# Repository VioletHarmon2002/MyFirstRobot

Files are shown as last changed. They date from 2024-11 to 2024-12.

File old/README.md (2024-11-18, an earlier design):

# Little endian 2.0

A HvA IoT project by Timo Lambregts, Jayden van Oorschot, Luc Enderman, Floris Boers, Gjalt van der Meer, Ilias Takassa and Silvester Rademakers.

You can find all relevant documentation 
[here](https://faaxeeheeqee80-iot-2023-2024-semester-2-group-pr-eb151c272401a9.dev.hihva.nl/)

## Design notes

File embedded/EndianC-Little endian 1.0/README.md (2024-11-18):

# Little endian base files

This repository contains the base design files and custom arduino libraries to create and work with the little endian robot.

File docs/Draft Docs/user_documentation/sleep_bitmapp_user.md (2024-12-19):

## User Documentation

### Using the Sleep Emote
The sleep emote is a visual representation of a sleeping state for the robot. 

#### Activating the Sleep Emote
To activate the sleep emote:

1. Ensure your device is powered on and connected to the OLED display.
2. Send the "sleep" command to your device using website of the project, for example.
3. The OLED display should now show the sleep emote.

### Troubleshooting
If the sleep emote doesn't display correctly:

1. Verify that the `sleep_bitmap.h` file is in the same directory as your main sketch.
2. Check that the bitmap dimensions are correct and match the actual size of your bitmap data.
3. Ensure that the OLED display is properly connected and initialized in your code.

### Customization
If you wish to modify the sleep emote:

1. Open the `sleep_bitmap.h` file in a text editor.
2. Modify the bitmap data array to change the appearance of the emote.
3. Ensure that the `sleep_width` and `sleep_height` definitions match your modifications if you change the size of the bitmap.

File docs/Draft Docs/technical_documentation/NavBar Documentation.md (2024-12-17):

# Overview

This script dynamically loads a navigation bar into the webpage and sets the active link based on the current page. It ensures that the correct nav link is highlighted, providing a visual to the user about their current location within the website

# Code breakdown

**Event Listener** : `document.addEventListener("DOMContentLoaded", function ()`

**Fetch NavBar.html**: 
```
fetch('NavBar.html')
.then(response => response.text())
.then(data => { document.getElementById('navbar').innerHTML = data;
```

- This fetches the `NavBar.html` file.
- Converts the response to text
- Inserts the fetched file's content into the element with the ID `navbar`

**Determine the current page**

With this code `const currentPage = window.location.pathname.split("/").pop();` The current page's filename is fetched from the URL

**Map pages to link ID's**

```
const pageToLinkMap = {
    "arrows.html": "robot-controls-link",
    "blocky.html": "block-editor-link",
    "connect.html": "connect-robot-link",
};
```

Then we get the active Link ID using this line

`const activeLinkId = pageToLinkMap[currentPage];`

Then we use the current pag'es filename to get the link ID from the `pageToLinkMap`

**Set the active link**

With this code we set the active link

```javascript
if (activeLinkId) {
    const activeLink = document.getElementById(activeLinkId);
    if (activeLink) {
        activeLink.classList.add("active");
    }
}
```

**Error Handling**

With this line we handle the errors incase the link doesn't exist

`.catch(error => console.error('Error loading navbar:', error));`

# Navigation Buttons to Nav Bar [#144]
The navigation buttons have been replaced with a responsive top navigation bar for seamless navigation across pages. The existing NavBarLoader functionality has been retained to dynamically highlight the current page.

**For Developers**
Changes Made:

1. HTML:  
Added a <nav> element with structured navigation links inside an unordered list (<ul>).

````
<nav id="navbar">
    <ul class="nav-list">
        <li><a href="arrows.html" id="robot-controls-link" class="nav-link">Robot Controls</a></li>
        <li><a href="blocky.html" id="block-editor-link" class="nav-link">Block Editor</a></li>
        <li><a href="connect.html" id="connect-robot-link" class="nav-link">Connect</a></li>
    </ul>
</nav>
````

2. CSS:  
Styled the navbar for a horizontal layout with hover effects, active link indicators, and responsive design for smaller screens.

````
.nav-list { list-style: none; display: flex; gap: 24px; }
.nav-link:hover { color: var(--color-sweet); }
.active { border-bottom: 2px solid var(--color-sweet); }
````

**For Users**  
- Improved Navigation: The navigation bar is fixed at the top for easy access across all pages.  
- Interactive Design: Hover effects and active link highlighting enhance usability.  
- Responsive Layout: Adapts seamlessly to various screen sizes for a consistent experience.

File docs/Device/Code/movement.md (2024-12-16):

# Robot Movement
### Walking Function Refactoring  
I implemented the forward-walking functionality for the robot and documented the progress in [User Story #114](https://gitlab.fdmci.hva.nl/IoT/2024-2025-semester-1/group-project/poonuugaaqii15/-/issues/114).

#### Key Changes:
- **Modular Design:**  
  - Extracted the `walkForward` function from the main file to a separate header file to improve code organization and readability.  
  - Created a dedicated **`walking.h`** file to encapsulate walking-related functions.

#### Benefits:
- **Clean Codebase:** The main file is now more concise and focused.  
- **Future Expansion:** The `walking.h` file provides a reusable structure for implementing additional walking movements.
---

### Issues Encountered and Fixes Implemented

#### 1. **Incorrect Use of `switch` with Strings**
- **Issue:**  
  The function `getCommand` attempted to use a `switch` statement with `String` objects, which is not supported in C++.
  
  ```cpp
  Command getCommand(const String& command) {
    switch(command) {  // Error: switch cannot be used with strings.
      case "forward":
        return FORWARD;
      // ...
    }
  }
  ```
  
- **Solution:**  
  Replace the `switch` statement with a series of `if-else` conditions or use a `std::map` for cleaner implementation.

  **Updated Code Example:**  
  ```cpp
  Command getCommand(const String& command) {
    if (command == "forward") return FORWARD;
    else if (command == "backward") return BACKWARD;
    // ... other conditions
    else return UNKNOWN;
  }
  ```

#### 2. **Duplicate Command Check**
- **Issue:**  
  The `"dance"` command was repeated in the conditional statement, which could lead to redundancy and confusion:
  
  ```cpp
  } else if (command == "forward" || command == "backward" || command == "dance" || command == "dance") {
  ```

- **Solution:**  
  Remove the duplicate `"dance"` condition to simplify and avoid redundancy.

  **Corrected Code Example:**  
  ```cpp
  } else if (command == "forward" || command == "backward" || command == "dance") {
  ```

#### **Key Takeaways:**
- **C++ Limitations:** Remember that `switch` statements do not support strings; use `if-else` or lookup structures instead.
- **Code Review:** Always review conditional statements for duplicate checks to ensure efficiency and clarity.

---  

### Laying Down Function Refactoring
I implemented the lieDown function so that the robot can lay down: [User Story #106](https://gitlab.fdmci.hva.nl/IoT/2024-2025-semester-1/group-project/poonuugaaqii15/-/issues/106).

#### For Developers
The lieDown function is placed in a separate header file (lieDown.h) for maintainability and reusability. Separating this functionality from the main file makes the codebase more organized and easier to modify. By storing the servo angles in an array, the function is both readable and simple to adjust.

**How It Works:**

The lieDown function accepts four servo objects representing the legs of the robot:  

- Front Left (FL)
- Front Right (FR)
- Rear Left (RL)
- Rear Right (RR)

The predefined servo positions for the lying-down motion are stored in the lieDownPositions array:  
{0, 180, 180, 0}.  

These correspond to specific angles for each leg:  

- 0° for the Front Left leg
- 180° for the Front Right leg
- 180° for the Rear Left leg
- 0° for the Rear Right leg

When the function is called, each servo is commanded to move to the assigned angle using the write method.

#### For End Users
The lieDown function allows the robot to smoothly transition into a lying-down position. This motion should be visually natural, with each leg moving to a predefined angle.

**How It Works:**

- Upon activating the "lie down" command, the robot's legs are adjusted via its servo motors to specific angles.  
- The motion ensures that the robot adopts a stable and balanced lying posture.

**Key Features:**

- The function ensures smooth movement of the robot.
- Predefined positions make the movement accurate and repeatable.
- The design is efficient, enabling reliable execution of the lying-down motion.

### Sit Function
The sit() function is designed to move the servos of the robot to predefined positions that simulate a sitting posture. It is part of the Movement class and works with initialized servo motors to adjust the robot's legs accordingly.

#### For Developers  
**How it Works:** The function writes specific angles to each servo based on predefined "sit" positions stored in an array:

````
 int sitPosition[] = {110, 40, 70, 145}; // Angles for FL, FR, RL, RR servos
````

These values correspond to the optimal configuration for a sitting position.

**Function Details:**

````
void sit();
````

- Location: Defined in movement.cpp.  
- Access: Public method in the Movement class.  
- Purpose: Moves the robot into a seated position by writing specific angles to each leg servo.

#### For End Users  
**What it Does:** Transitions the robot into a sitting position by moving its legs to predefined angles.  
**When to Use:** Use this function when you want the robot to adopt a seated posture for resting or stabilization. The movement can be controlled via the web application when the "sit" command is pressed. The robot dog will then follow the instruction.

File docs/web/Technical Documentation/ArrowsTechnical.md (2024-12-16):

# Technical Documentation of arrows HTML

### Overview

This code provides a web-based control page for the robot, allowing users to issue commands for animations, emotes and movement through buttons. These commands are sent to the server using a TCP socket.

#### HTML Structure

- Container for Buttons: Groups buttons for animations, emotes, and movement into distinct sections.

- Button Elements: Each button sends a specific command to the server when clicked.

#### Key Classes:

- `.animate-container`: Contains buttons for animations.
- `.emote-container`: Contains buttons for emotes.
- `.arrow-container`: Contains directional movement buttons.

#### Supported Commands

- **Animation commands**: `Stand`, `Sit`, `Lay`, `Wave`
- **Emote commands**: `Smile`, `Frown`, `Cry`, `Sleep`
- **Movement commands**: `Forward`, `Backward`, `Left`, `Right`

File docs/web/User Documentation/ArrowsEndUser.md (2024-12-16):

# End user documentation

### Purpose

This interface allows you to controll a robot's movements, animations and emotes using simple buttons.

#### Features

1. **Animations**
    - `Stand`: Makes the robot stand upright.
    - `Sit`: Puts the robot in a seated position.
    - `Lay Down`: Makes the robot lie down.
    - `Wave`: The robot waves its paw.

2. **Emotes**
    - `Smile`: The robot displays a smiling expression.
    - `Frown`: The robot shows a frowning expression.
    - `Cry`: The robot simulates crying.
    - `Sleep`: The robot enters a sleeping pose.

3. **Movement**
    - `Direction controls`: Buttons to move the robot forward, backward, left or right

#### Troubleshooting

1. **No response from robot**
    - Ensure the robot is powered on and connected to the network

2. **Error messages**
    - `Failed to create socket`: The control page has an issue, try restarting it.
    - `Failed to connect to server`: The robot is either offline or there is something wrong with the server

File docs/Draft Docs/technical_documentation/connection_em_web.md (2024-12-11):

# Documentation for Robot Network Code

## Overview
This project establishes a robot’s network connectivity and command-handling capabilities, with key components for Wi-Fi management and WebSocket communication. It uses modular classes for better separation of concerns and code readability.

---

## WebSocket Handler
The `WebSocketClient` class in **`websocket_handler.cpp`** handles WebSocket communication with a remote server.

### Key Features
- **Connect to a server**:
  - `Connect()` establishes a WebSocket connection with the server.
  - `Reconnect()` retries connecting if the connection is lost.
- **Send and receive data**:
  - `SendData(const String& data)` sends JSON data to the server.
  - `ReadData()` reads JSON data from the server, deserializing it to extract the command.
- **Connection management**:
  - `IsConnected()` checks the connection status.
  - `CloseConnection()` safely disconnects the client.

### Code Highlights
#### Constructor
```cpp
WebSocketClient::WebSocketClient(const char* ip, uint16_t port) 
    : server_ip(ip), server_port(port) {}
```
Initializes the WebSocket client with server IP and port.

#### JSON Handling in `ReadData`
```cpp
DynamicJsonDocument doc(1024);
DeserializationError error = deserializeJson(doc, json);
if (error) {
  Serial.print("JSON deserialization failed: ");
  Serial.println(error.c_str());
  return;
}
```
Parses incoming JSON strings to extract commands, while handling deserialization errors.

---

## Wi-Fi Manager
The `WiFiManagerHelper` class in **`wifi_manager.cpp`** manages Wi-Fi connectivity using the WiFiManager library.

### Key Features
- **Automatic Wi-Fi connection**:
  - `connectToWiFi(const char* ssid)` attempts to connect to a specified Wi-Fi network, retrying up to 5 times.
- **Custom callbacks**:
  - `setOnConnectionFailedCallback(std::function<void()> callback)` allows specifying a custom action for connection failures.
- **Access to Wi-Fi client**:
  - `getClient()` provides a reference to the `WiFiClient` instance for use in other modules.

### Code Highlights
#### Connection Retry Logic
```cpp
for (int attempt = 1; attempt <= maxRetries; ++attempt) {
    if (wifiManager.autoConnect(ssid)) {
        Serial.println("Connected to WiFi");
        return true;
    } else {
        Serial.printf("Connection attempt %d failed, retrying...\n", attempt);
        delay(retryDelay);
    }
}
```
This loop attempts reconnection, providing feedback on each attempt.

---

## Main Program
The main program (**`main.cpp`**) integrates Wi-Fi and WebSocket components while coordinating robot functionalities such as movement and face display.

### Wi-Fi Manager Integration
#### Connecting to Wi-Fi
```cpp
if (!wifiManagerHelper.connectToWiFi()) {
    Serial.println("Wi-Fi connection failed");
    ESP.restart();  // Restart ESP32 if Wi-Fi connection fails
}
```
Ensures the robot is connected to Wi-Fi and restarts if the connection cannot be established.

### WebSocket Handler Integration
#### Establishing Connection
```cpp
if (!wsClient.Connect()) {
    Serial.println("Failed to connect to the server");
    ESP.restart();  // Restart the ESP32 if connection fails
}
```
Connects to the server on startup and restarts if the connection fails.

#### Receiving Commands
```cpp
if (wsClient.IsConnected()) {
    String command = wsClient.ReadData();
    setFace(command);
    handleCommand(command);
}
```
Handles incoming JSON commands, updating the robot’s face and movements based on the received instructions.

---

## Dependencies
- **WiFiManager**: Simplifies Wi-Fi connection setup.
- **ArduinoJson**: Enables parsing and serialization of JSON data.
- **Wire**: Handles I2C communication for sensors and displays.
- **ESP32Servo**: Manages servo motors for movement.

---

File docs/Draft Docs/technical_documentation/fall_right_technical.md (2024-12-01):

# `fall_right.h` Technical Documentation

## Overview  
The `fall_right.h` file defines a function to initiate a controlled fall of the robot to its right side using servo motors. The ESP32Servo library is used for servo control, ensuring precise positioning of the robot.

---

## Dependencies  
- **Library**: `ESP32Servo.h`  
  Required for controlling servo motors on ESP32 devices.

---

## Constants

const int fallRightPositions[4] = {0, 0, 180, 180};

- Defines the servo positions for a controlled right-side fall.
- The order of servo positions:
  1. **FL** - Front Left (0°)
  2. **FR** - Front Right (0°)
  3. **RL** - Rear Left (180°)
  4. **RR** - Rear Right (180°)

---

## Functions

### `void fallRight(Servo& FL, Servo& FR, Servo& RL, Servo& RR)`  
Initiates the robot's fall to the right by setting the servo motors.

#### Parameters:
- **`FL`**: Front Left servo motor
- **`FR`**: Front Right servo motor
- **`RL`**: Rear Left servo motor
- **`RR`**: Rear Right servo motor

#### Behavior:
1. **Prints**: "Falling to the right" to the serial monitor for debugging.

---

## Example Usage

#include <ESP32Servo.h>
#include "fall_right.h"

// Servo Initialization
Servo frontLeft;
Servo frontRight;
Servo rearLeft;
Servo rearRight;

void setup() {
    Serial.begin(9600);
    
    // Attach servos to appropriate pins
    frontLeft.attach(2);  // Example 
    frontRight.attach(4); // Example 
    rearLeft.attach(5);   // Example 
    rearRight.attach(18); // Example 
}

void loop() {
    // Trigger the controlled fall
    fallRight(frontLeft, frontRight, rearLeft, rearRight);
    delay(5000);  // Delay for demonstration
}
```

---

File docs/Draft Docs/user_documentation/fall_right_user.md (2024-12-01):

# Fall Right Module - User Documentation

## Overview

The Fall Right module provides a function to adjust the servos of the Little Endian robot when it is falling to the right. This function is intended to be used as part of a larger system that detects falls and triggers appropriate responses.

## Features

- Adjusts the servos to predefined positions to help stabilize the robot.
- Simple integration with existing servo control systems.

## How to Use

1. **Setup**: Ensure that the servos are properly connected to the robot's control board and are initialized using the `ESP32Servo` library.
2. **Function Call**: Use the `fallRight` function to adjust the servos when a right-side fall is detected.
3. **Integration**: Integrate this function into your fall detection system to automatically trigger servo adjustments.

## Troubleshooting

- **Servo Movement Issues**: If the servos do not move as expected, check the connections and ensure the servos are properly initialized.

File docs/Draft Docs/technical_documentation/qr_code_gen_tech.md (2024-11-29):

# Description

This code generates a QR code from the MAC address of an ESP32 device and prints it to the Serial Monitor.
The QR code is displayed using ██ for black modules and spaces for white modules. This will turn into the QR code that end users will scan to controll the robot.

## Dependencies

- `Wifi.h`: Library for WiFi functions.
- `qrcodegen.h`: Library for generating QR codes.

## Functions

`void printQRCode(const uint8_t qrcode[])`

This function prints the QR code to the Serial Monitor.

- int size = qrcodegen_getSize(qrcode): Retrieves the size of the QR code.
- Serial.print("QR code size: "): Prints the size of the QR code.
- for (int y = 0; y < size; y++): Iterates over each row of the QR code.
- for (int x = 0; x < size; x++): Iterates over each column of the QR code.
- Serial.print(qrcodegen_getModule(qrcode, x, y) ? "██" : " "): Prints ██ for black modules and spaces for white modules.

## Example output

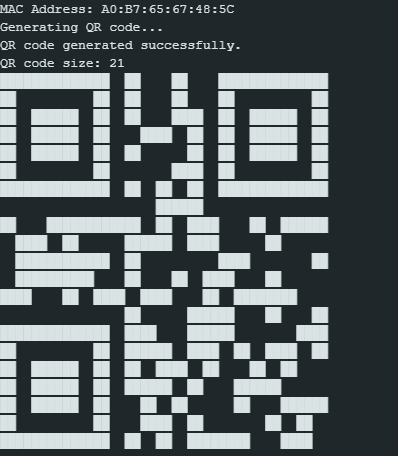
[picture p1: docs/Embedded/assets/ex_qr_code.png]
Example output


## Source code

```c++
void setup() {
  Serial.begin(115200);

  delay(1000);

  WiFi.mode(WIFI_MODE_STA);
  WiFi.begin();

  delay(100);

  String macAddress = WiFi.macAddress();

  Serial.println("MAC Address: " + macAddress);

  const int bufferSize = qrcodegen_BUFFER_LEN_FOR_VERSION(3);
  uint8_t qrcode[bufferSize];
  uint8_t tempBuffer[bufferSize];

  Serial.println("Generating QR code...");
  bool success = qrcodegen_encodeText(macAddress.c_str(), tempBuffer, qrcode, qrcodegen_Ecc_LOW,
                                      qrcodegen_VERSION_MIN, qrcodegen_VERSION_MAX, qrcodegen_Mask_AUTO, true);

  if (success) {
    Serial.println("QR code generated successfully.");
    printQRCode(qrcode);
  } else {
    Serial.println("Failed to generate QR code.");
  }
}
```

```c++
void printQRCode(const uint8_t qrcode[]) {
  int size = qrcodegen_getSize(qrcode);
  Serial.print("QR code size: ");
  Serial.println(size);
  for (int y = 0; y < size; y++) {
    for (int x = 0; x < size; x++) {
      Serial.print(qrcodegen_getModule(qrcode, x, y) ? "██" : "  ");
    }
    Serial.println();
  }
}
```

## Steps to generate QR Code

#### prerequisites

1. Download the zip of the qr code generator library by nayuki at this 
[link](https://github.com/nayuki/QR-Code-generator)

2. Follow these steps for the library:
- Extract the zip file
- Copy the `c` folder
- Paste the `c` folder in the `libraries` folder of Arduino IDE, usually located at `Documents/Arduino/libraries`
- Rename the `c` folder to `QRCode`
- Remove the `qrcodegen-demo` and the `qrcodegen-test` files

#### Generate QR code

1. Upload the code to your board:
- Connect your board(e.g ESP32) to your computer
- Open the Arduino IDE
- Copy and paste the code
- Upload the code to your board
2. Open the serial monitor:
- After uploading the code, open the serial monitor
- set the baud rate to `115200`
3. Generate the QR code
- The board will display a mac adress
- it will then generate a QR code from the MAC adress and print it to the serial monitor.

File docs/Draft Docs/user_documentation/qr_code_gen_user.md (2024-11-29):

# End User Documentation

## Description

This document provides instructions for connecting to and controlling a robot using a QR code generated by the ESP32. The QR code contains the id of the ESP32, which is used to establish a connection.

## Connecting to the robot

1. Scan the QR Code:

- Use a QR code scanner on your smartphone or a dedicated QR code scanning device.
- Scan the printed QR code to connect to the robot

2. Control the Robot:

- Once connected, you can use the robot control application to send commands to the robot.
- Use the provided controls to control the robot.

## Example QR Code

Here's an example of what the QR code might look like:

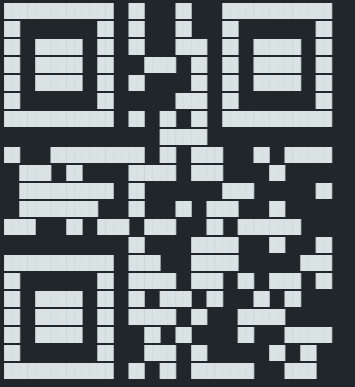
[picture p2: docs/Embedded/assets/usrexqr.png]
ExampleQRCode


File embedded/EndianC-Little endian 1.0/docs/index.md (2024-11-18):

## Motor_test

An arduino sketch to test the steppermotors and the shift registers

## Accelstepper

Copy this folder to your Arduino/libaries folder for the LEAccelStepper to work. This is the original Accelstepper library with a small change to make it possible to extend it and use shift registers.

Read the original [AccelStepper documentation](https://www.airspayce.com/mikem/arduino/AccelStepper/) for more information.

## PCB Design

The PCB contains the following components:

### 74HC595 shift register

This component is used so the WEMOS D1 Mini needs less pins to control the steppermotors. The shift register is connected to the WEMOS D1 Mini with the following pins:

| WEMOS D1 Mini | 74HC595 |
| --- | --- |
| D0 | DS |
| D4 | SCHP |
| D5 | STCP |

By setting these 3 pins HIGH or LOW in a specific order, you can control the 8 output pins of the shift register. 

### ULN2003A transistor array

This component is used to control the steppermotors by diverting power directly from the battery or USB to the stepper motor coils. The ULN2003A is connected to the shift register in the following way:

| 74HC595 | ULN2003A | motor |
| --- | --- | --- |
| Q0 | IN1 | Motor 2, Pin 4 |
| Q1 | IN2 | Motor 2, Pin 3 |
| Q2 | IN3 | Motor 2, Pin 2 |
| Q3 | IN4 | Motor 2, Pin 1 |
| Q4 | IN5 | Motor 1, Pin 4 |
| Q5 | IN6 | Motor 1, Pin 3 |
| Q6 | IN7 | Motor 1, Pin 2 |
| Q7 | IN8 | Motor 1, Pin 1 |

### RGB LED

An WS2812 RGB LED is connected with its datapin to pin D4 on the WEMOS. You can use the Adafruit NeoPixel library to control the LED.

### Battery

The PCB can be powered by four AA batteries. The batteries are connected to the PCB with a JST connector. The battery power can be switched on or off using a switch between connected to `JP3`.

### External devices

The I2C (SCL and SDA) pins of the WEMOS are connected to multiple JST connectors in order to connect external peripherals. These pins (D1 and D2) can also be used as GPIO pins.

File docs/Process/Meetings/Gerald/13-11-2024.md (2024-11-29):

# Meeting Gerald 13 November

Continue on the existing assignment. The documentation is already present. 

**Problems:**

- Not really usable for the target audience
- Non functional web app
- Not working with multiple robots.
- Design flaws hardware robot
- Capacitors for voltage drop servos
- Motions hardcoded c
- Array of commands 
- Full control in the web app
- Mobile app developed
- Visual language: code blocks
- Robot design flaws:
    - 2 different servos, plastic and iron belt servos
    - Should be more sturdy legs(cat legs instead of straight)
    - Robot face
        - Not redefinable 
        - Hardcoded
        - Led matrix
        - Cuter
        - 3d instead of 2d
    - No api for extra sensors or resistors
        - Mobile app doesn't know 
        - Codeblocks doesn't know
- Lithium ion battery

2 times per sprint show code gerald. Should be working on geralds laptop, 
Sprint 2 and 3 its mandatory.

Start with docker env. 

Create new robots from scratch. 

Define coding standards

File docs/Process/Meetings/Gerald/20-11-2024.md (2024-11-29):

# Meeting Gerald 20 November

Create a requirement list from the last interview. Add new requirements to the existing list.

Smart mobilities, why the robot should follow the other bots, because it fits in the theme.

**User Stories:**

- Follow: Avoid other dogs, to not run into other dogs. NOT IMPORTANT
- Robot Line: lower prio
- QR codes: for ease of use, other way around
- Joystick: 
- Walking: mid, basic stuff high
- Guide: instead of manual use a video
- Improved API: name wrong, don't bother user with api stuff

**Joystick:**

- Joystick for when a phone is turned sideways.
- Joystick mode or the block program mode.
- Split joystick into movements and actions
- Joystick and codeblocks, at same time, or after each other
- Joystick high and blockly low. Because a joystick is used for user control.

Replace battery, has to be able to power future sensors.

Follow hbo ict style guide for website

First user stories are epics. Quite big
No use of backend, use environment

**Database:**

- Uptime
- Uuid
- Name

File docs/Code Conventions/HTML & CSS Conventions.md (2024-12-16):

# HTML Conventions

1. **HTML Structure**
    - Properly nest elements.
    - Indent child elements with 2 spaces to show hierarchy.
    - Close all void elements (e.g., `<br />`, `<img />`) for consistency.

2. **Lowercase Tags and Attributes**
    - Always use lowercase for tag and attribute names.
    - Example: ``

3. **Attribute Quotes**
    - Always use double quotes for attributes.
    - Example: `<input type="text" placeholder="Enter your name">`

4. **Meaningful Element Names**
    - Use semantic elements (`<header>`, `<footer>`, `<article>`, etc.) wherever possible.
    - Example: 
    ```HTML
    <main>
        <section>
            <h1>Welcome</h1>
        </section>
    </main>
    ```

    # CSS Conventions

1. **Selectors**
    - Keep selectors short, meaningful, and lowercase.
    - Avoid deeply nested selectors (limit nesting to 2 levels if possible).

2. **Naming Classes and ID's**
    - Use `kebab-case` for class and ID names.
    - Example: `.button-primary {color: #fff;}`

3. **Formatting Rules**
    - Write one declaration per line, and seperate rule blocks with a black line.
    - Indent rules with 2 spaces.
    - Example: 
    ```CSS
    .example-class {
        background-color: #f4f4f4;
        color: #333;
    }

    .another-class {
        margin: 10px 0;
    }
    ```

4. **Avoid Inline Styles**
    - Define all styles in external stylesheets to maintain separation of concerns.

    **For more info please visit the page down below, these are the most important conventions for our project that are taken out of this page.**

    [HTML & CSS Code conventions](https://google.github.io/styleguide/htmlcssguide.html#HTML_Style_Rules)

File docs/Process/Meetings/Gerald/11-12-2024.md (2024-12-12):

# Meeting Gerald 11 December

- Search function is redundant. We should keep Gerald 'in the loop' about these types of features.
- We should invite the client for the next sprint review.
- We have the wrong prios; We should focus on getting the movement done and focus on the robots instead of the visuals of the website.
- We should keep eachother updated about the robots, ordered parts and other embedded related stuff.
- Need to make sure the robots are easy to assemble and disassemble.
- We are free to create an API, but it shouldn't be a seperate user story, but an integration into the criteria of the user story
- Highest prios are now Movement, Animations, and then Emotes respectively. 
- We need to finish things for the AUAS open day.
- We planned a sprint review with Gerald on Monday 12/11/2024 10:20

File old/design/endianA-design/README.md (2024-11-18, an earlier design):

# 3D design
In this file i will explain the process of the 3D design for each Endian

## A:
Little Endian A has been defined as a three wheeled robot with one DC motor in the back to drive two wheels, and a servo in the front to steer the front wheel.
The design first started with a small drawing:
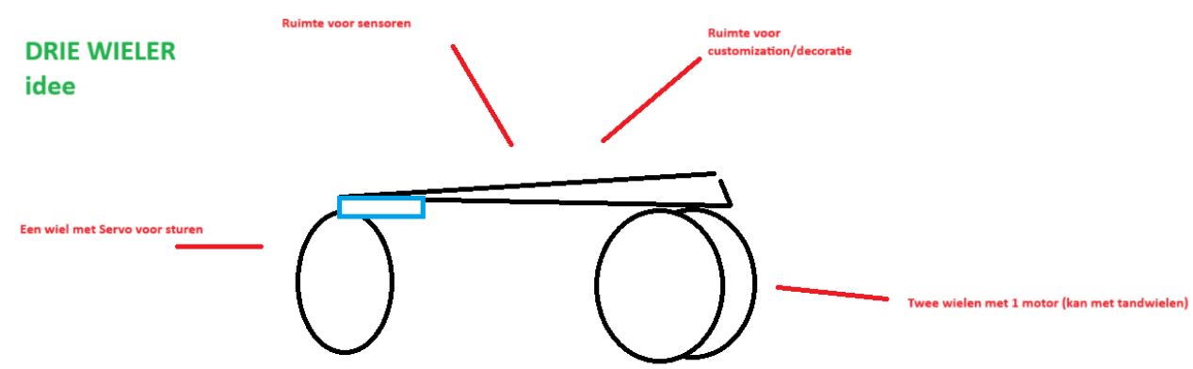
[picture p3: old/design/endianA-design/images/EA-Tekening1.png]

This is the first 3D design, it is done to test the concept. It will be done using 3D printing to test hardware and for ease of use. Later we will design something that uses more sustainable materials like plexiglass or wood. The front wheel has been discarded for now so that we can focus on the back part, instead it has a small sled that is only used to steer.
It must be noted that this is a extreme prototype and may not resembles the final prototype/product.
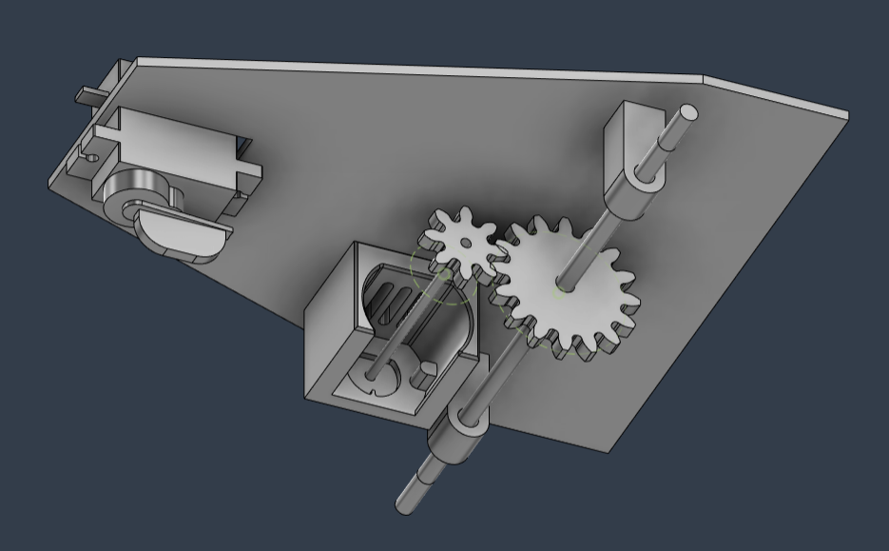
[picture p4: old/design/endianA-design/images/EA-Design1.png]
Design1


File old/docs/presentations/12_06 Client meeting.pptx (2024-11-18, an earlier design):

## Little Endian 2.0

Floris Boers, timo Lamberts, Gjalt van der Meer,
Jayden van Oorschot, Silvester Rademakers, Ilias Takassa

12-06-2024

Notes: Jayden

## Inhoudsopgave

- Epics, Sub - Epics en User Stories
  - Assembly
  - Hoofd
  - Code blocks
  - Communication
  - Buttons
- Vragen

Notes: Jayden

## Epics: Assembly

Epic:

Sub-epic:

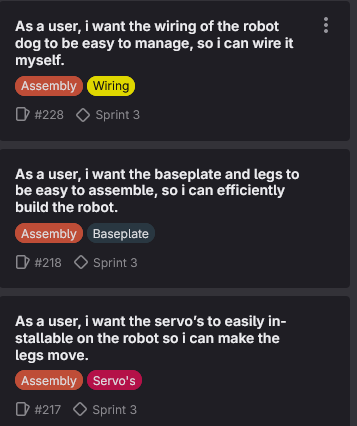
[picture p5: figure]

User stories:

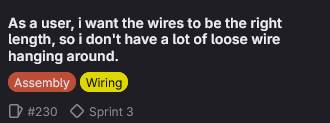
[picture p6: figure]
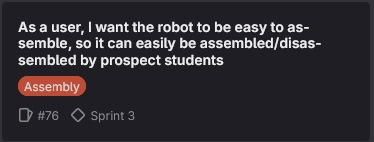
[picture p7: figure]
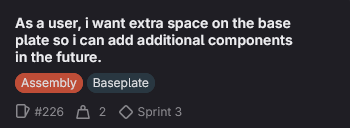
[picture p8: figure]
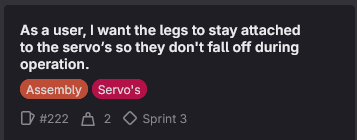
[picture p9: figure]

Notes: Silvester

## Epic: Hoofd

Epic: Sub epic: User stories:

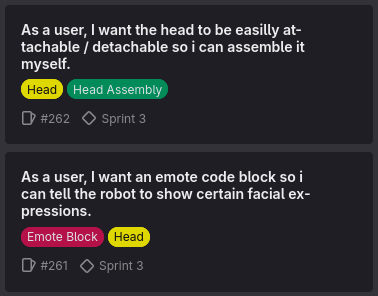
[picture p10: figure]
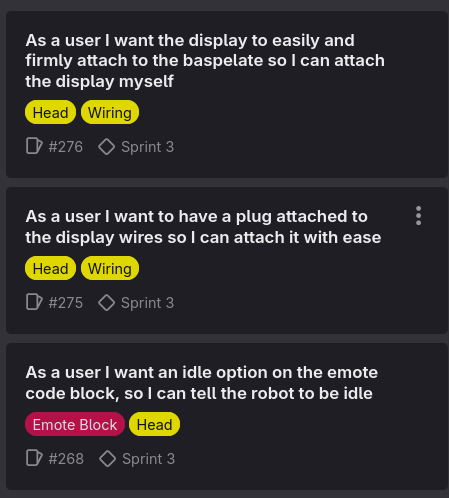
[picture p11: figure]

Matrix(€4) of oled(€7)?

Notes: Timo

## Epic: Code Blocks

Epic:

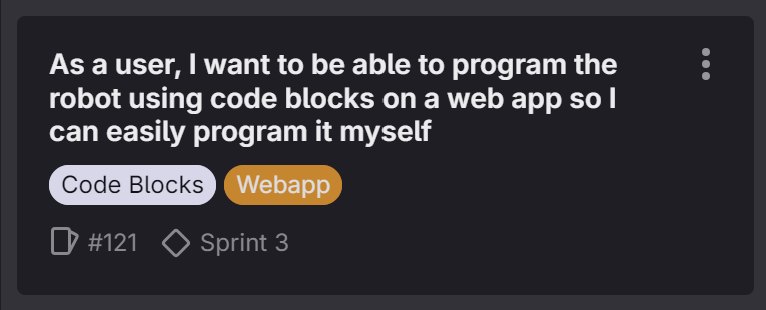
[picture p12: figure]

Sub - epic:

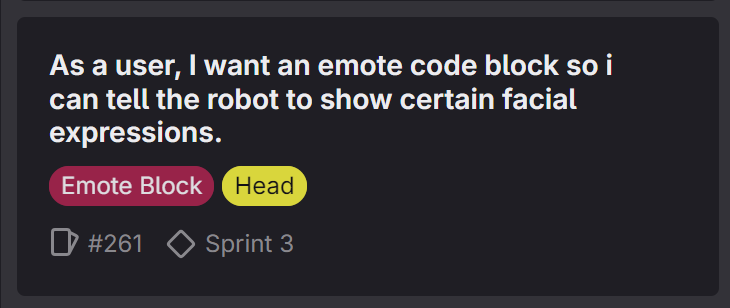
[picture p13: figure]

User stories:

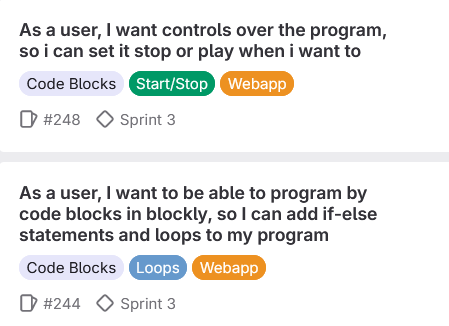
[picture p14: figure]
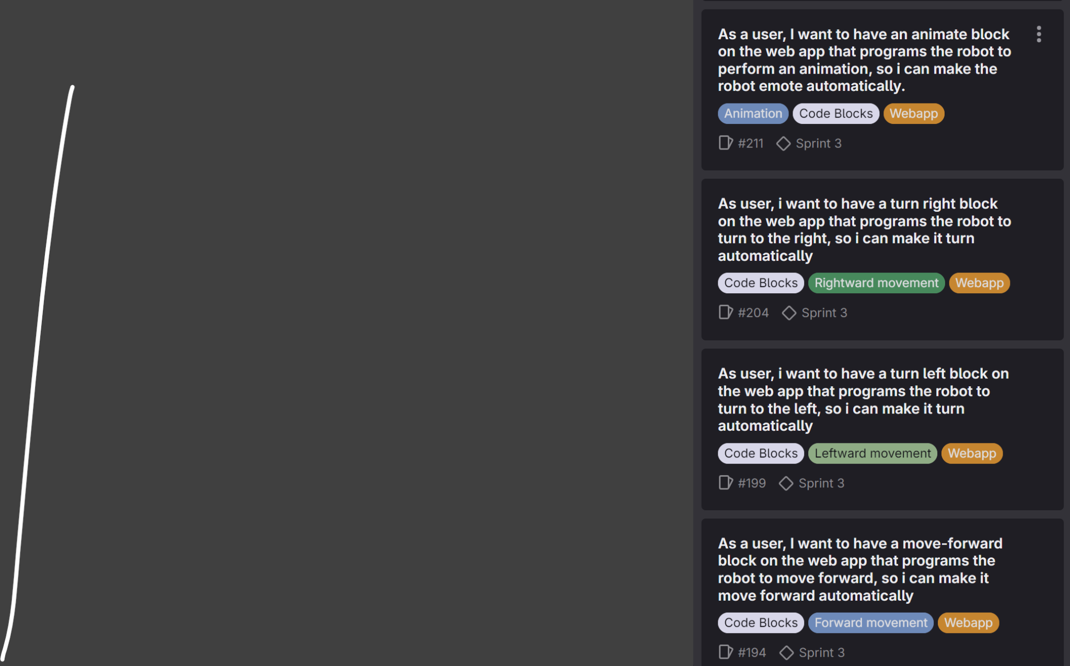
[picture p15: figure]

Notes: Floris

## Epic: Communication

Epic:

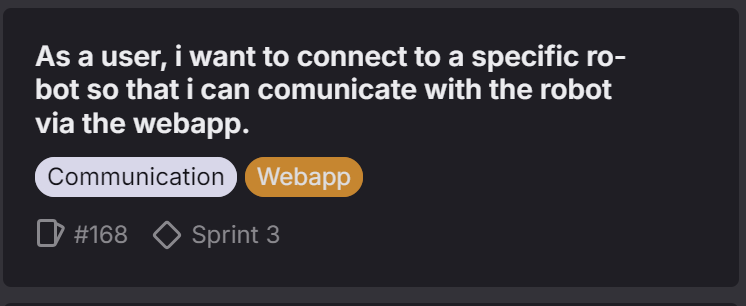
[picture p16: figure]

Sub - Epic:

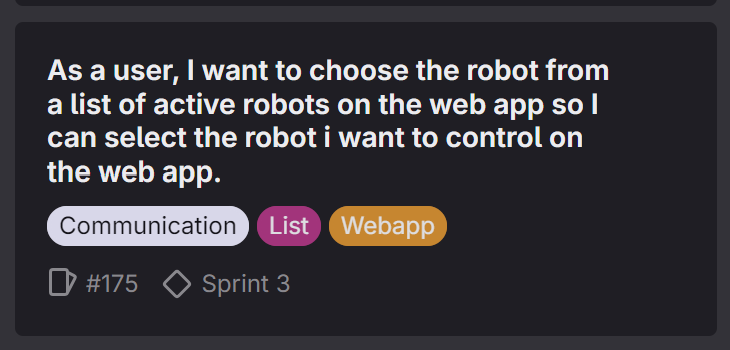
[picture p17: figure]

User stories:

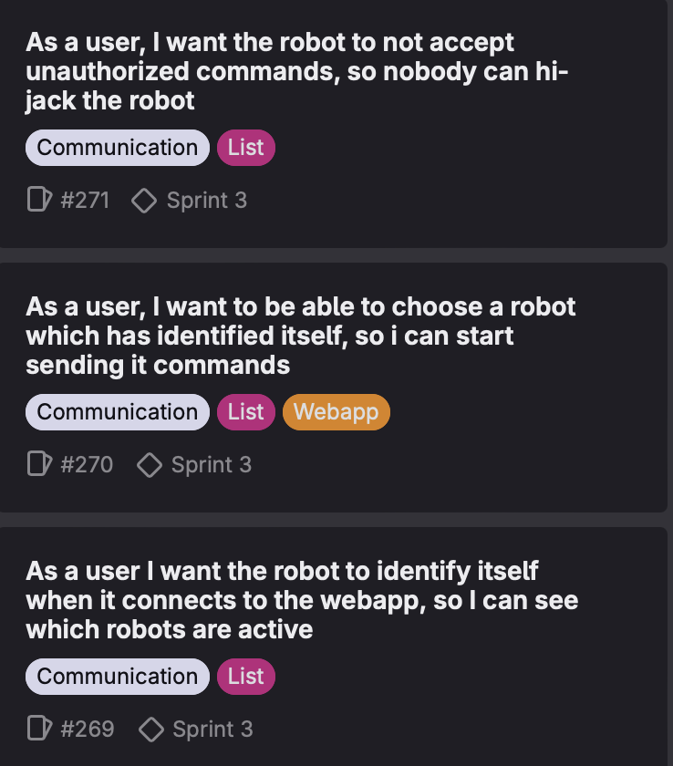
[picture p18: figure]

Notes: Ilias

## Epic: Buttons

Epic:

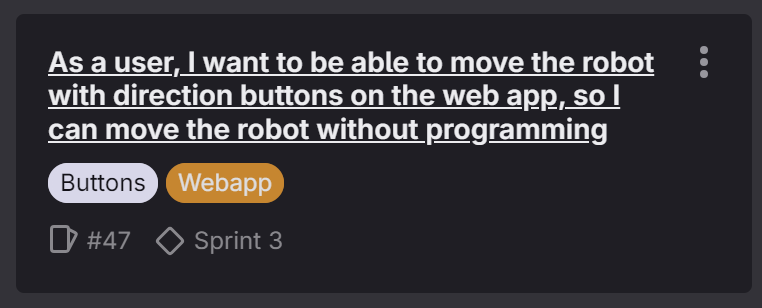
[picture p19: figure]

Sub - epic:

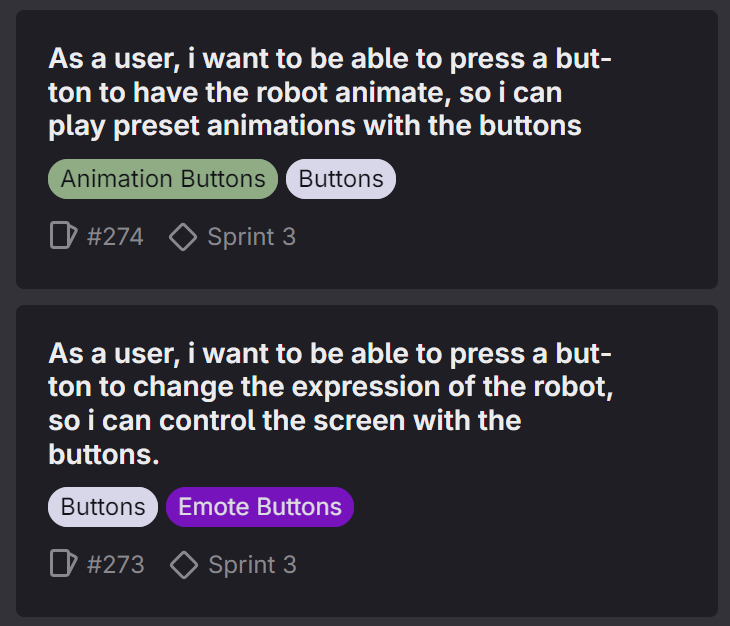
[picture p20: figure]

User stories:

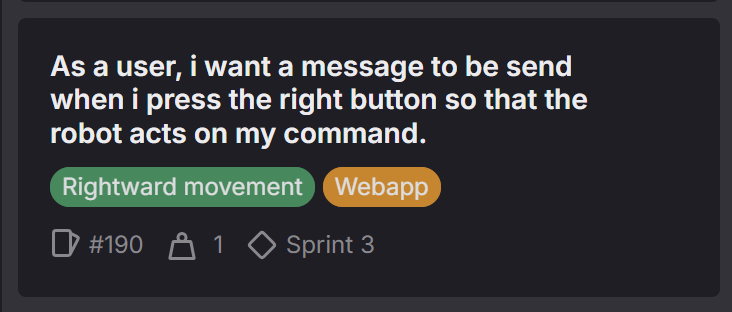
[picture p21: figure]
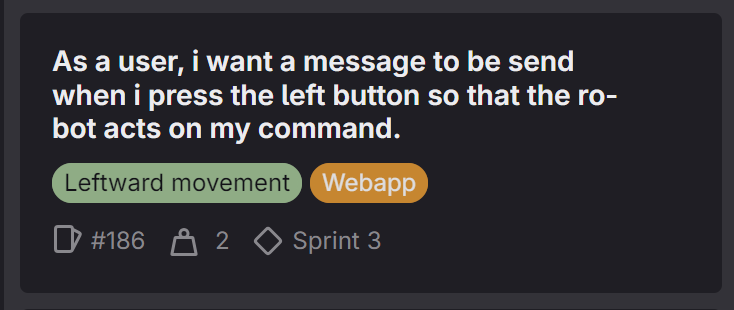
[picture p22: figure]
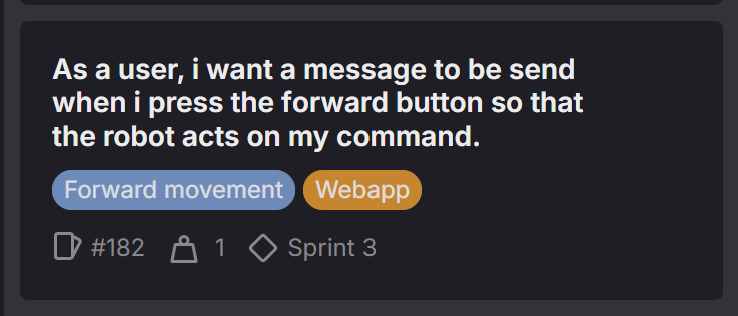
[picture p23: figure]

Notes: Gjalt

## Sprint 3: Planning

Nieuwe rollen

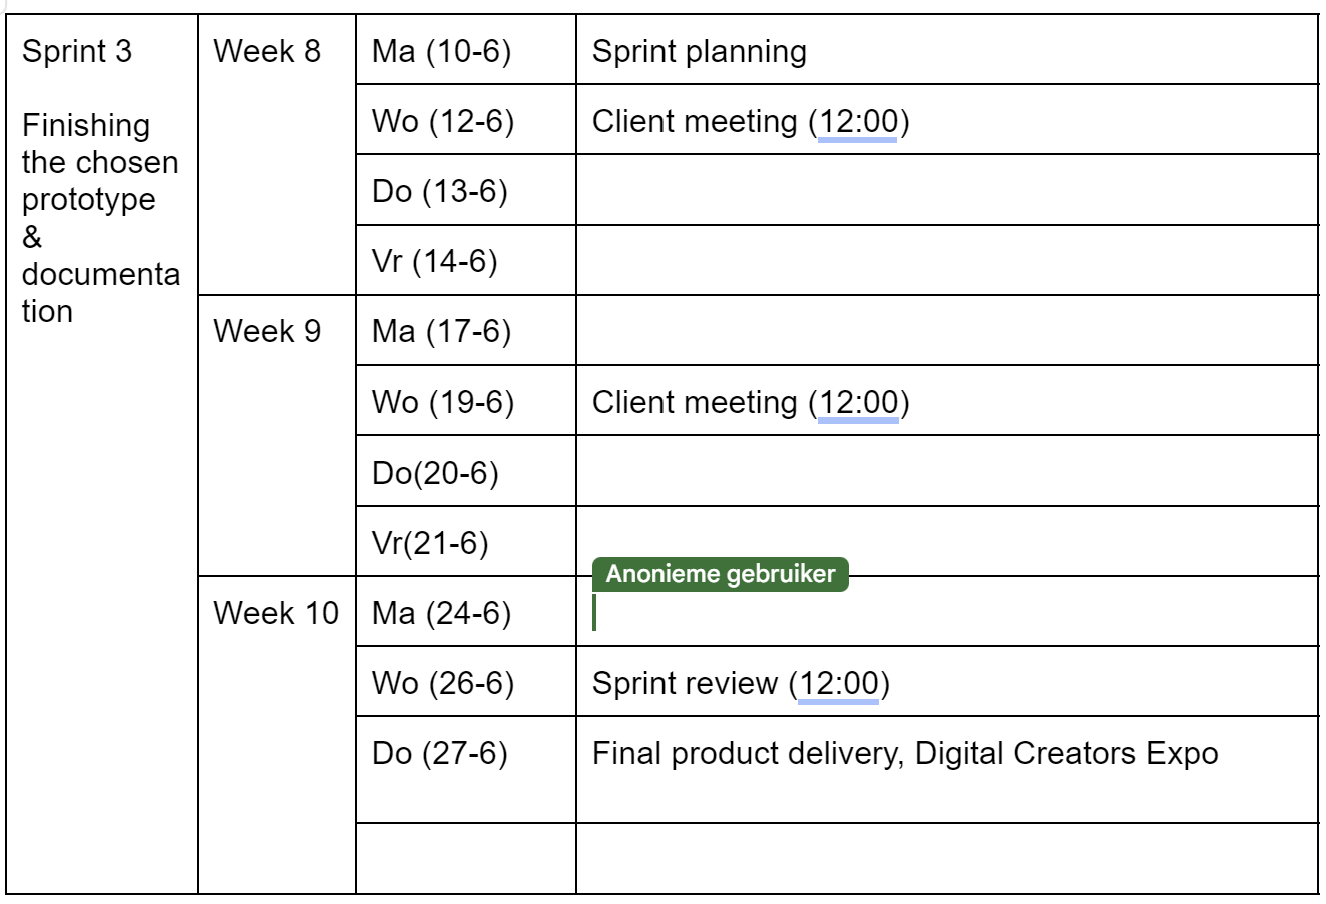
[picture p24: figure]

## Bedankt voor het luisteren


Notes: Gjalt

## Vragen?

User blog:MrFlamerBoy/Dancing Question Mark. | Battle for ...

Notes: Gjalt

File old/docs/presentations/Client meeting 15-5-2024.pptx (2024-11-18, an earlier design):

## Client meeting

Team Little Endian
Jayden van Oorschot, Timo Lambregts, Gjalt van der Meer, Luc Enderman, Floris Boers,
Silvester Rademakers & Ilias Takassa

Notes: Silvester

## Inhoudsopgave

- Hoe is deze sprint gegaan?
- Wat gaan we volgende sprint doen?
- De planning voor volgende sprint
- Project update

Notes: Silvester

## Sprint 1


- Veel moeite gehad met textbook scrum
- Learning process
- Veel research gedaan
- Endian A loopt achter

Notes: Luc

## Sprint 2 - planning


- Robot kiezen
- Communicatie webserver
- gekozen robot verder ontwikkelen

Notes: Luc

## Webserver

- buttons kunnen nog niet communiceren met robot
- websockets geïmplementeerd in server maar werkt nog niet helemaal


## Endian A


Three wheeler Endian
Progress: slow, but steady


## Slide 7


3D printed wheel
(screw on)

Easy put on motor
holder

Cogs for speed and power

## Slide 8


## Endian B

- De robot is hetzelfde als vorige week.
- Componenten zijn gemonteerd
- Stukje code gemaakt om te proberen te lopen

## Endian C

- Originele Endian werkt weer
- Code van de original Endian wordt geleerd zodat we het kunnen sturen d.m.v. commando’s.


## Voor & nadelen per prototype

| Endian A | Endian B | Endian C
Voordelen | Vereist weinig hardware componenten, waardoor de BOM goedkoop is i.v.m. andere prototypes. | Meeste progress. slaat aan op wow factor. | Voortborduren op bestaand werk.
Nadelen | Minste voortgang. (nog) geen werkend prototype. | Veel servo’s waardoor we snel aan het budget per prototype zitten. | Veel bugs om te fixen in originele ontwerp

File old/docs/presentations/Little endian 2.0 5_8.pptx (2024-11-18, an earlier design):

## Little endian 2.0

## Endian A

- Prototype
- Research om de motor te verbeteren

## Endian B

- Blueprint gemaakt
- Eerste prototype
- Poten nog in development

## Endian C

## Webpage

- Communicatie
- Server opzetten

## General research

- Onderzoek over materialen kosten
- Onderzoek over een balans tussen budget en eco vriendelijkheid
- Wow factor

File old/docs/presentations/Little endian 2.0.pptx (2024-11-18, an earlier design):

## Little endian 2.0

Robot ideeën

## Materialen

Om de auto nog zo sterk mogelijk te houden en relatief goedkoop
Denken wij dat multiplex de beste optie is. (ook beter voor natuur)
Acrylaat 60x60 3mm = 16.00 EU
Multiplex 60x60 4mm = 5.00 EU


## Crawler bot

Avg price: €12,50 -> €7,00 wemos d1 mini, €4,50 const. Servo, battery holder €0,80, etc…


## DIY Smart watch


- Display would cost around 7 euros on tiny tronics, but one euro on Aliexpress.
- Including D1 mini plus screen, the total price would be 14eur/product for the necessary hardware alone

## Crawler

A bot with semicircle wheels / wheels with 2 servo’s / 2 dc motors and a
Motor controller.


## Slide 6


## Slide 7

Avg cost: 16.55 euro plus additional cost for extra sensors/acuators


## Parts list and prices


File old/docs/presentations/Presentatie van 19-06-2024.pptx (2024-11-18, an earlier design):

## Little Endian 2.0

Floris Boers, Timo Lambregts, Gjalt van der Meer,
Jayden van Oorschot, Silvester Rademakers, Ilias Takassa, Luc Enderman (MIA)

19-06-2024

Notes: Silvester

## Inhoudsopgave:

- Epics - Hoofd - Code blocks - Communication - Movement
- Accelerometer
- Power supply
- Outro

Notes: Silvester

## Epic: Hoofd

Epic: Sub epic:

design:


- Gekozen voor Oled
- Lachen, slapen, zielig kijken zijn expressies tot nu.
- Verschillende expressies gemaakt met bitmaps


demo!


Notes: Gjalt

## Epic: Code Blocks

Epic:


User stories done:


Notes: Floris

## Epic: Communication

Epic:


Sub - Epic:


User stories:


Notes: Ilias

## Epic: Direct movement

Epic:


Sub - epic:


User stories:


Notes: Floris

## Accelerometer

- MPU9250
- Accelerometer, gyroscope, temperatuur, magnetometer
- We kunnen gegevens lezen
- Wordt niet gebruikt bij lopen
- Animaties blijven hardcoded


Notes: Jayden

## Power supply

- Voltage divider
- Voltage regulator
- Stroom circuit op protoboard integreren

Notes: Jayden

## Bedankt voor het luisteren


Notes: Timo

## Vragen?

User blog:MrFlamerBoy/Dancing Question Mark. | Battle for ...

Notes: Timo

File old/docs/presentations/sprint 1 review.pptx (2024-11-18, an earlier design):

## Little Endian Sprint 1 review

Floris Boers, Luc Enderman, timo Lamberts, Gjalt van der Meer,
Jayden van Oorschot, Silvester Rademakers, Ilias Takassa

17-05-2024

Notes: Silvester

## Table of content

- Sprint 1 overview
- Planning sprint 2
- Webserver
- Tribot
- Robot dog
- Endian classic (O.G)
- Prototypes vergelijken
- Conclusie & aanbeveling

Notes: Silvester

## sprint 1 overview

- Twee unieke prototypes ontworpen en in elkaar gezet.
- Onderzoek over milieuvriendelijkheid, budget, wow-factor, communicatie, lasersnijden en het verbeteren van bestaande ontwerpen
- Front-end ontwerp voor de website
- Code geschreven voor de prototypesUser stories en GIT verbeterd
- Documentatie
- Onze user stories herzien en verbeterd zowel als onze GIT

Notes: Luc

## planning sprint 2


- Gekozen robot verder ontwikkelen.
  - Webserver verder ontwikkelen
  - Communicatie verder ontwikkelen
  - Design/model verder ontwikkelen
  - Functionaliteit en uitbreidbaarheid verder ontwikkelen.
- Scrum proces volgens clients eisen doorzetten.
  - User stories als epic met label epic
  - Eerst user story basis en daarna uitbreiden
  - Laat de user stories ongeveer halve dag duren
  - Geen nieuwe stories tijdens sprint

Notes: Luc

## Webserver

## Webserver


- User stories zijn te groot


## Tribot


- Stabiele driewieler robot
- Erg simpel en makkelijk te maken
- Veel ruimte voor uitbreidbaarheid


## TriBot: User story voorbeeld


## Robot dog


- Robot hond geïnspireerd door filmpje van WEGSTR CNC
- Eigen design dat aan eisen voldoet
- 4 poten aan servo’s
- Werkend prototype

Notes: Jayden

## Robot dog: user/learning stories

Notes: Jayden

## Endian classic (O.G)

- De originele little endian gemaakt door Bas Pijls
- Originele bijgeleverde software functioneel
- Nagedacht over potentiële verbeteringen
- Nog niets toegepast

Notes: Timo

## Endian classic (O.G)


User stories

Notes: Timo

## Comparing prototypes


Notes: Gjalt

## Conclusie & aanbeveling

- Moeite met scrum maar door sprint heen wel vooruitgang
- Ontwikkelen van 3 prototypes tegelijkertijd ging redelijk.
- Te veel ingezet op hosting direct opzetten.
- Samenwerking verliep goed.
- We raden aan om niet verder te gaan met Classic (O.G.)
- We raden aan om in sprint twee verder te gaan met één prototype.

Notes: Gjalt

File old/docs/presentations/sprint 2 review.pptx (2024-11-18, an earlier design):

## Little Endian 2.0 Sprint 2 review

Floris Boers, Luc Enderman, timo Lamberts, Gjalt van der Meer,
Jayden van Oorschot, Silvester Rademakers, Ilias Takassa

07-06-2024

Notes: Luc

## Inhoudsopgave

- Sprint 2 overview
  - Aan welke epic hebben we gewerkt
  - Waar liepen we tegenaan
- Planning sprint 3
  - Eventueel nieuwe epics
  - Requirements
- Conclusie
- vragen

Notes: Luc

## Sprint 2 overview

Epics:
- #76 As a user, I want the robot to be easy to assemble, so it can easily be assembled by prospect students. (Assembly)
- #121 As a user, I want to be able to program the robot using code blocks on a web app so I can easily program it myself. (Code blocks)
- #168 As a user, i want to connect to the robot so that i can communicate with the robot via the web app. (Communication)
- #57 As a user, I want to be able to move the robot with direction buttons on the web app, so I can move the robot without programming. (Buttons)

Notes: Gjalt

## Epic: assembly

As a user, I want the robot to be easy to assemble, so it can easily be assembled by prospect students
Progress:
- De servos makkelijk te installeren
- Protoboards gemaakt
- Design steving
- Loopt goed en ziet er natuurlijk uit
To do:
- Ruimte voor uitbreiding
- Kabels nog niet ingekort

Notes: Silvester

## Epic: code blocks

As a user, I want to be able to program the robot using code blocks on a web app so I can easily program it myself
Progress:
- Code blocks zijn volledig functioneel
- Code blocks wordt vertaald naar auto-generated code
- Code can be sent
To-do:
- Alle code blocks moeten berichten sturen

Current code block features:
- Move forward
- Turn left/right
- Print
- Wait
- Animate

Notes: Floris

## Epic: communication

As a user, I want to connect to the robot so that i can communicate with the robot via the webapp
Progress:
- De robot kan verbinden met de webapp
- De front-end kan post requests versturen naar de API
- De API kan de post requests verwerken en via websocket versturen naar de robot
To do:
- Implementeren van sessies
- Commands moeten naar één specifieke robot verstuurd worden

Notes: ilias

## Epic: buttons

As a user, I want to be able to move the robot with direction buttons on the web app, so I can move the robot without programming
Progress:
- Functionele knoppen voor de front end
- Berichten worden gestuurd van de website naar robot
To-Do:
- Knoppen voor animaties
- Beter uxd

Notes: Timo

## Waar liepen we tegenaan?

- Sommige user stories duurde langer dan gedacht.
- Laten lopen van robot Dog viel tegen.
- Minder consistent met stand-ups
- Merge conflicts

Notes: Gjalt

## Planning sprint 3

- 1 week meer dan verwacht
- Nieuwe rollen: Product owner: Timo Scrum master: Silvester Git master: Jayden


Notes: Jayden

## Requirements

Verwijderen:
#4 The price per robot must be as low as possible (maximum €20)

#14 The robots are selected on the webapp by scanning the QR codes printed on them

#17 The robot can be controlled with a virtual joystick on the webapp

Toevoegen:
- Stap voor stap handleiding, om makkelijk in elkaar te kunnen zetten
- De robot moet er meer levend uitzien, dmv een gezicht.

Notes: Jayden

## Conclusie

- Scrum ging goed deze sprint (soms nog wel lastig in te schatten hoeveel user stories haalbaar zijn)
- Goeie voortgang op prototype geboekt
- Demo!

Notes: Gjalt

## Bedankt voor het luisteren


## Vragen?

User blog:MrFlamerBoy/Dancing Question Mark. | Battle for ...

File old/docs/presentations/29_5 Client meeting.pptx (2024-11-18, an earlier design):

## Client meeting

Team Little Endian
Jayden van Oorschot, Timo Lambregts, Gjalt van der Meer, Luc Enderman, Floris Boers,
Silvester Rademakers & Ilias Takassa

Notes: Silvester

## Inhoudsopgave

- Planning 3
- Updated requirements 4 - 5 - 6
- Updated epics 7
- Progress website 8
- Progress communicatie 9
- Progress Robot dog 10 - 11

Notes: Silvester

## Planning


- Sprint is op de helft
- Vorige week weinig user stories gedaan
- Veel tijd gebruikt voor scrum
- Deze week wel veel user stories gedaan, daar gaan we mee verder

## Updated requirements


- Nieuwe tabel toegevoegd met robot functionalities
- Epics bij requirements gezet

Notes: Jayden

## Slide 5

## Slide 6


## Updated epics


- Alle epics verbeterd
- Sub epics toegevoegd
- User stories herschreven & nieuwe toegevoegd


## Progress website



## Progress communicatie

- Communicatie tussen de front-end and API werkt
- Het is mogelijk om verbinding te maken via websocket
- Communicatie API en websocket werkt nog niet


## Progress Robot dog design



## Progress Robot dog movement


- Liggen
- Zitten
- Zwaaien
- Staan op start positie
- Loopt
- Draait
- maar nog niet heel goed


## Bedankt?

## vragen?

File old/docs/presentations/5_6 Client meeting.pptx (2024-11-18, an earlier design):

## Client meeting 05/06

Team Little Endian 2.0
Jayden van Oorschot, Timo Lambregts, Gjalt van der Meer, Luc Enderman, Floris Boers,
Silvester Rademakers & Ilias Takassa

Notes: Jayden

## Inhoudsopgave

1. User stories die we gedaan hebben
2. Burndown chart
3. Epic progress
4. Requirement updates
5. Slot


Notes: Jayden

## User story stats

30 User stories gesloten deze week
Goeie vooruitgang geboekt

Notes: Jayden is gay, Timo

## Burndown chart

- Te veel nieuwe issues aangemaakt
- Vaak te lang gewacht met het “sluiten”
- 20 ‘user stories’ zijn (sub-) epics


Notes: Ilias

## Epic: Assembly

- Paar elementen geredesigned
- Schroeven toegevoegd zodat alles makkelijk bij elkaar blijft
- Batterij
- Zijkanten
- Protoboard
- Design heeft KERF geïmplementeerd


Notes: Luc

## Epic: Web app

- Werkende communicatie
  - Nog wel simpele communicatie
  - Geen prive sessies
  - Nog niet beveiligd
- Mooie landingspagina


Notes: Timo

## Epic: Blocks

- Blockly geimplementeerd
- Animatie blockly aanwezig met alle opties
- Functie “sendCommand” nog worden aangemaakt om te kunnen versturen naar de API
- Volle functionaliteit


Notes: Floris

## Protoboard

- 2 extra protoboards voor 2 extra robot’s


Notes: Gjalt

## Epic: Robot movement

- Werkende robot movement
- Docker environment aangemaakt
- Wanneer website lokaal gehost word kan er een “forward”, “leftward” en “rightward” command verstuurd worden naar een dummy robot


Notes: Gjalt

## Requirement updates

- Microcontroller moet een V in pin hebben
- Het design moet stevig zijn
- Boven en onderplaat worden aan elkaar bevestigd met schroeven
- Microcontroller en componenten verbonden via protoboard
- Code blocks werken d.m.v. Blockly (non-functional)

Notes: Silvester

## Slecht nieuws…

Luc vakantie


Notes: Luc

## Bedankt voor het luisteren


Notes: Silvester

## Vragen?

User blog:MrFlamerBoy/Dancing Question Mark. | Battle for ...

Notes: Silvester

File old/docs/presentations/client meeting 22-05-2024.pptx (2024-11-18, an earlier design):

## Client meeting

Gjalt van der Meer, Ilias takassa, Jayden van Oorschot, Luc Enderman, Silvester Rademakers, Floris Boers & Timo Lambregts

22-05-2024

## Inleiding

- Gekozen robot
- Planning voor sprint 2
- Epics
- Userstories
- Planning Scrum

## Robot Dog - Little Endian 2.0

Gekozen voor de robot hond.
- Grootste en makkelijkste wow factor
- Al veel voortgang
- Ontwerp heeft ruimte voor verbetering

## Planning sprint 2


- De basis functionaliteiten van de hond uitwerken
- Basis functionaliteit website maken
- Eventuele animaties voor de hond
- Draadloze communicatie

## Epics


- Gebaseerd op (functional) requirements
- Allemaal vanuit user

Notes: Jayden

## Voorbeeld user story met epic


## Planning / aanpak scrum

- Nieuwe scrum master en product owner
- Dagelijkse stand-up
- Betere epics en kleinere user stories

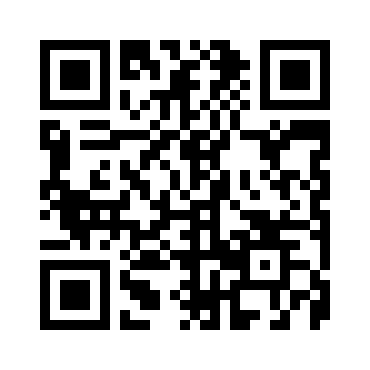
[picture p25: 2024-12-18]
t.png

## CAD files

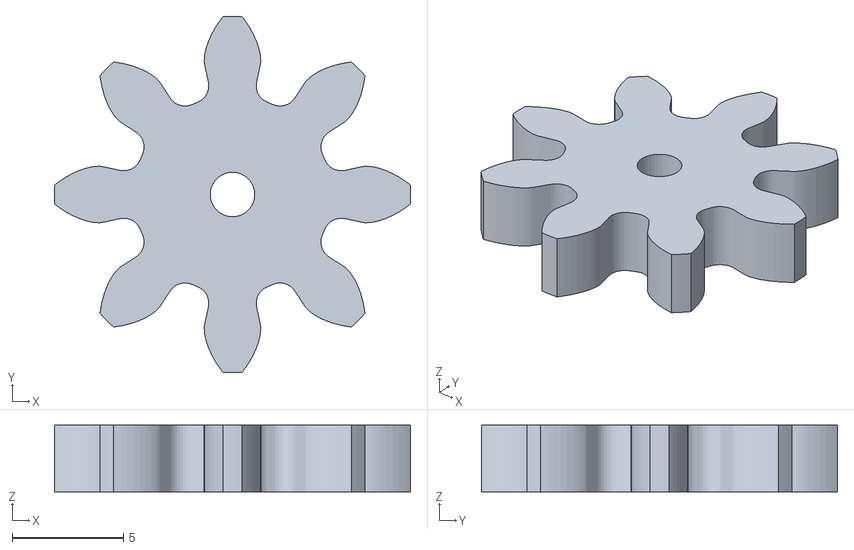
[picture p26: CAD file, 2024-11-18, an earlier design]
old/design/endianA-design/STLS/EndianA/Batch1/Spur Gear (8 teeth).stl
16.0 x 16.0 x 3.00

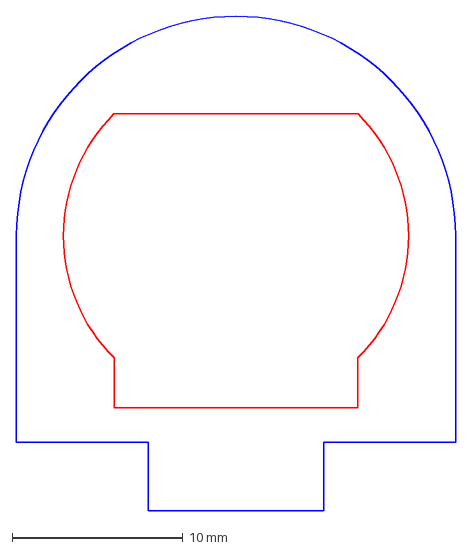
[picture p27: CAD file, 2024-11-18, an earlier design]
old/design/endianA-design/STLS/EndianA/Batch2/motorholder2.dxf
25.7 x 28.9 mm

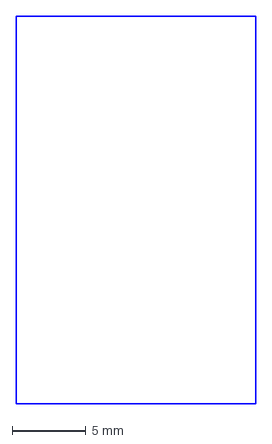
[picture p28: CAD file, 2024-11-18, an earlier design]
old/design/endianA-design/STLS/EndianA/Batch3/groeve-plate.dxf
16.2 x 26.3 mm

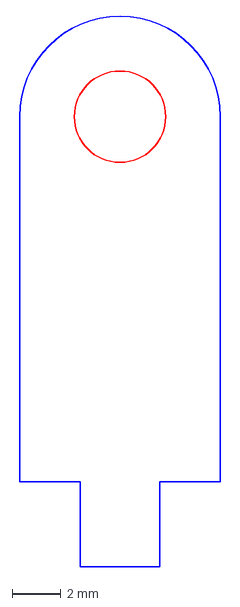
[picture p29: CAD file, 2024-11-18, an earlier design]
old/design/endianA-design/STLS/EndianA/LaserCut-1/AxelHolder.dxf
8.25 x 22.6 mm

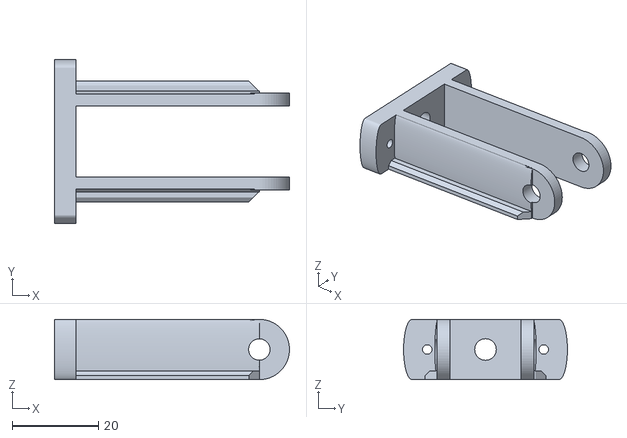
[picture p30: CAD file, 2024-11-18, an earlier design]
old/design/endianA-design/STLS/EndianA/wheels/rw_bike_front_fork_1x.stl
54.5 x 38.0 x 14.0

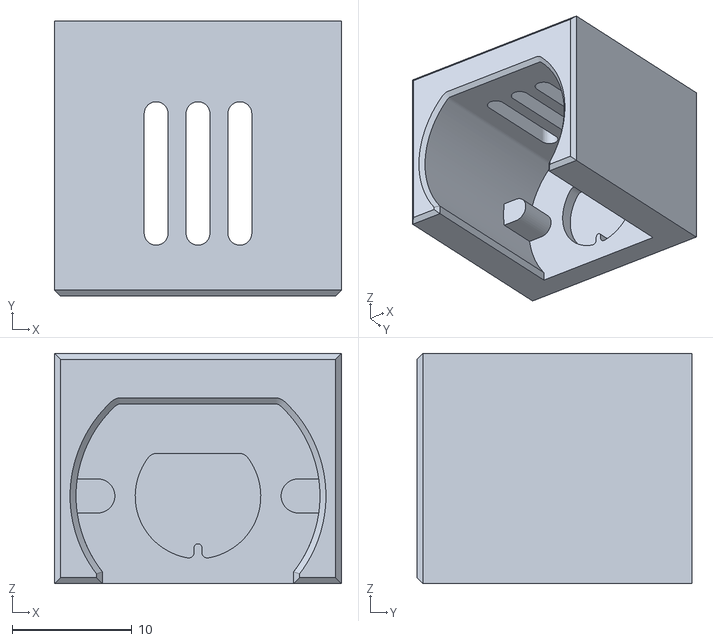
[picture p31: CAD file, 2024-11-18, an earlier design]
old/design/endianA-design/STLS/EndianA/Batch1/MotorHolder.stl
24.0 x 23.0 x 19.3

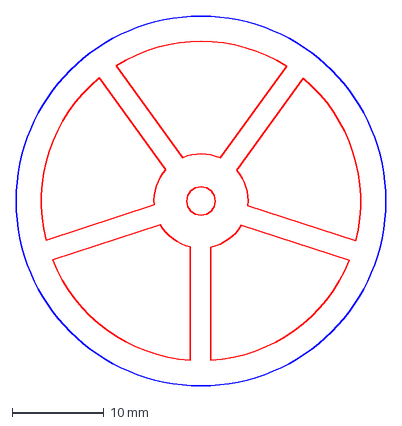
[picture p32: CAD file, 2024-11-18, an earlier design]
old/design/endianA-design/STLS/EndianA/Batch2/wiel.dxf
40.2 x 40.2 mm

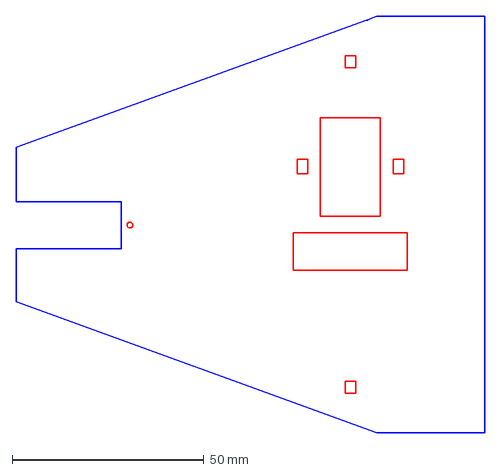
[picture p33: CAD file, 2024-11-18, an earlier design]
old/design/endianA-design/STLS/EndianA/Batch3/Body plate.dxf
122.2 x 108.7 mm

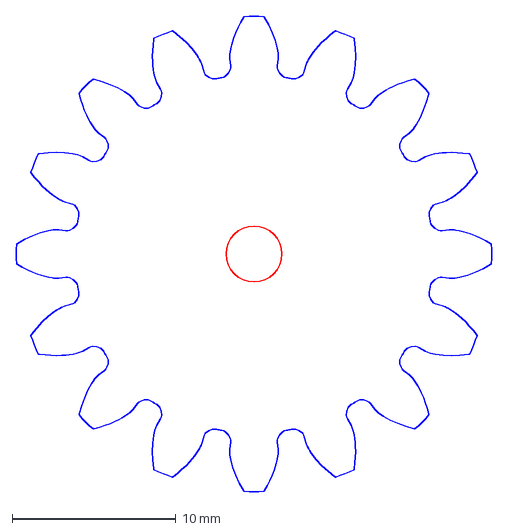
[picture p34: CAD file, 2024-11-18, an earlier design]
old/design/endianA-design/STLS/EndianA/LaserCut-1/BigCog.dxf
29.1 x 29.1 mm

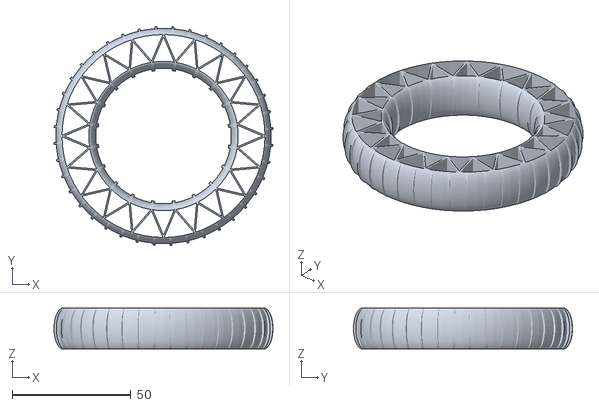
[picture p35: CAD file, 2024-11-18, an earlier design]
old/design/endianA-design/STLS/EndianA/wheels/rw_bike_rear_wheel_tire_tpu_1x.stl
92.2 x 92.2 x 17.2

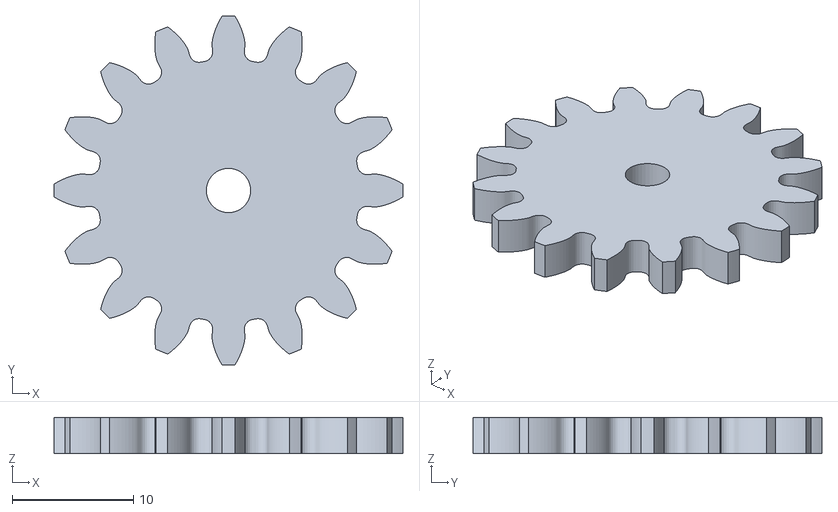
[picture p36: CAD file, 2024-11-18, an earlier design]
old/design/endianA-design/STLS/EndianA/Batch1/Spur gear 16 teeth.stl
28.8 x 28.8 x 3.00

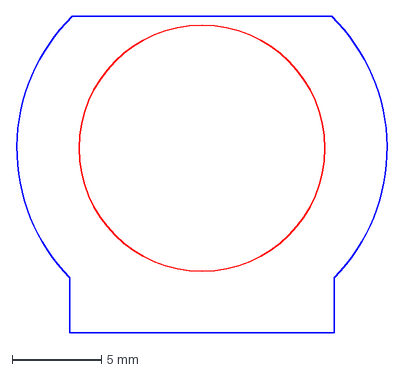
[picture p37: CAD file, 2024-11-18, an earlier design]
old/design/endianA-design/STLS/EndianA/Batch2/motorholder2-groeve.dxf
20.8 x 17.7 mm

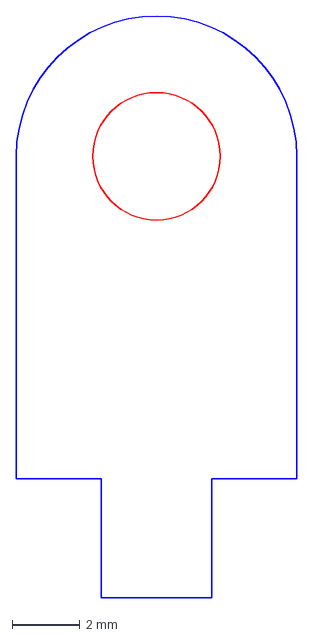
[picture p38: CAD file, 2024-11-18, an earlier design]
old/design/endianA-design/STLS/EndianA/Batch3/axel holder.dxf
8.25 x 17.1 mm

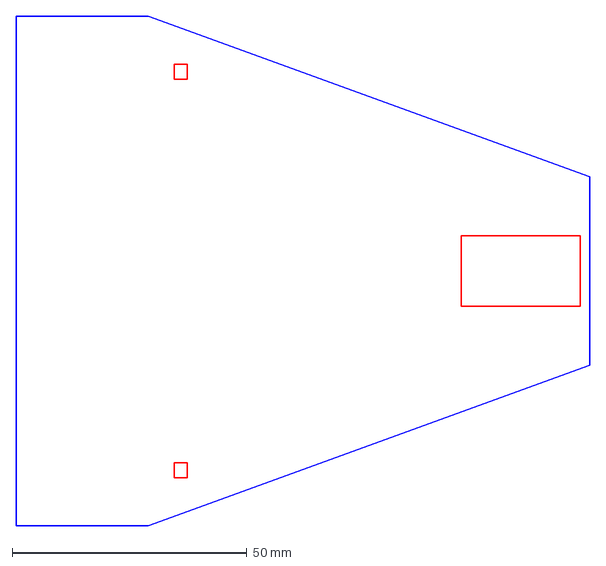
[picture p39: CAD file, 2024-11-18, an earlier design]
old/design/endianA-design/STLS/EndianA/LaserCut-1/BasePlate.dxf
122.2 x 108.7 mm

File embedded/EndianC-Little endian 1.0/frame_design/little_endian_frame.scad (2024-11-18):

$fn = 50;
frameWidth = 110;
frameDepth = 160;
wheelRadius = 18;
motorDepth = 15;
motorWidth = 17;
boltRadius = 1.5;
boltEdgeDistance = 6;
wheelCaseWidth = 41;
wheelCaseDepth = 36;
wheelCaseCenterY = 30;

frameFilletRadius = 10;
wheelCaseFilletRadius = 5;
centerBarWidth = 8;

motorBottom = 70;
motorLeft = frameWidth/2 - motorWidth;

penHoleDiameter = 15;

// Maak een "frame" vorm. Deze vorm komt ook terug in het gat voor de wielen
module frame(width, depth, filletRadius){
        topCircleCenterDepth = depth - width/2;
    
        // De vorm bestaat uit de omtrek van drie cirkels
        hull() {            
            translate([-width/2 + filletRadius, filletRadius, 0])
                circle(r=filletRadius);
            translate([width/2 - filletRadius, filletRadius, 0])
                circle(r=filletRadius);
            translate([0, topCircleCenterDepth, 0])
                circle(d=width);
         
    }
}   

// Maak een wiel
module wheel(radius, holeRadius, holeHeight){
    // wiel met gat
    difference(){
        circle(r=radius);
        circle(holeRadius);
    }
    
    // maak het gat "plat"
    translate([-holeRadius, holeHeight/2, 0])
        square([holeRadius*2, holeRadius*2]);
    
    translate([-holeRadius, -holeHeight/2-holeRadius*2, 0])
        square([holeRadius*2, holeRadius*2]);
    
    // Maak het wiel vast aan het frame
    translate([0, radius-1, 0])
        square([1,2]);
    translate([0, -radius-1, 0])
        square([1,2]);
}

// De uitsparing voor het blauwe gedeelte van de stappenmotor met gaten voor de tie-wraps
module motorHole(){
    translate([0, motorDepth/2, 0]){
        square([motorWidth, motorDepth]);
        translate([motorWidth/2-1, -5, 0])
            square([14, 3], center = true);
        translate([motorWidth/2-1, motorDepth+5, 0])
            square([14, 3], center = true);
    }
    
    
}

// Gebruik de modules om het frame te maken
difference(){
    // Het frame
    frame(frameWidth, frameDepth, frameFilletRadius);
    
    // De uitsparingen voor de wielen
    translate([centerBarWidth/2,wheelCaseCenterY,0])
        rotate([0, 0, -90])
            frame(wheelCaseDepth, wheelCaseWidth, wheelCaseFilletRadius); //rechts
    
    translate([-centerBarWidth/2,wheelCaseCenterY,0])
        rotate([0, 0, 90])
            frame(wheelCaseDepth, wheelCaseWidth, wheelCaseFilletRadius); // links
    
    // De uitsparingen voor de stappenmotoren
    translate([motorLeft, motorBottom, 0]) // rechts
        motorHole();
    
    scale([-1, 1, 1]) // spiegelen voor links
        translate([motorLeft, motorBottom, 0])
            motorHole();
    
    // Het gat voor de pen
    translate([0, motorBottom + motorDepth, 0])
        circle(d=penHoleDiameter);
        
    // gaten voor de "sliders"
    translate([0, frameDepth-boltEdgeDistance, 0]) //voor
        circle(r=boltRadius); 
        
    translate([0, boltEdgeDistance, 0]) // achter
        circle(r=boltRadius);
        
    

}

// Rechter wiel
translate([centerBarWidth/2 + wheelCaseWidth/2, wheelCaseCenterY, 0])
    wheel(wheelRadius, 2.5, 3);   

// Linker wiel
scale([-1,1,1]) // spiegelen
    translate([centerBarWidth/2 + wheelCaseWidth/2, wheelCaseCenterY, 0])
            wheel(wheelRadius, 2.5, 3);  

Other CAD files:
old/design/endianA-design/STLS/EndianA/wheels/rw_bike_rear_wheel_for_tpu_tire_1x.stl
old/design/endianA-design/STLS/EndianA/Batch1/axel.stl
old/design/endianA-design/STLS/EndianA/Batch2/motorholder1-groeve.dxf
old/design/endianA-design/STLS/EndianA/Batch3/bracket.dxf
old/design/endianA-design/Design/EndianA-V0.1.f3d
old/design/endianA-design/STLS/EndianA/Batch1/Plate.stl
old/design/endianA-design/STLS/EndianA/Batch2/baseplate.dxf
old/design/endianA-design/STLS/EndianA/Batch2/motorholder1.dxf
old/design/endianA-design/STLS/EndianA/LaserCut-1/SmallCog.dxf
old/design/endianA-design/STLS/EndianA/wheels/rw_bike_rear_wheel_tire2_tpu_1x.stl

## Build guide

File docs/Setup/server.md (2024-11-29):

# Server setup

## Run server
To start the server it starts with building and running the docker docker-compose file. This is done by running this command:
```
docker-compose up --build -d
```
Breakdown:

- docker-compose
    - This is the Docker tool that defines and runs multi-container Docker applications using the docker-compose.yml file.

- up
    - This command creates and starts containers based on the configuration in the docker-compose.yml file. If the containers are already running, it stops and recreates them.

- --build
    - Forces Docker Compose to build the images before starting the containers. This is useful if you’ve made changes to the Dockerfile or any related files and want to ensure the container uses the latest image build.

- -d (detached mode)
    - Runs the containers in the background (detached mode). This means the containers will continue running, and you can use your terminal for other tasks.

Equivalent Steps:

- docker-compose build (to build images)
- docker-compose up -d (to start services in the background)

---

## Dockerfile
This Dockerfile creates a Docker image based on Ubuntu, sets up an Apache web server with PHP, and includes custom files for a web application. Apache is used to serve the website stored in the container's ```/var/www/html/``` directory.

### **1. `FROM ubuntu`**
- **Base image:** Uses the official Ubuntu image as the starting point for building the custom Docker image.

### **2. `ENV TZ=Europe/Amsterdam`**
- **Environment variable:** Sets the time zone to Europe/Amsterdam.

### **3. `RUN ln -snf /usr/share/zoneinfo/$TZ /etc/localtime && echo $TZ > /etc/timezone`**
- **Time zone configuration:** 
  - Links the system's local time to the specified time zone.
  - Updates the `/etc/timezone` file with the correct time zone.

### **4. `RUN apt update && apt install -y apache2 apache2-utils libapache2-mod-php php-cli php-sockets && apt clean`**
- **Install necessary software:** 
  - Updates the package list.
  - Installs Apache2, utilities, and PHP modules.
  - Cleans up the package cache to reduce image size.

### **5. `COPY ../web/ /var/www/html/`**
- **Copy web files:** 
  - Copies the content from a local `../web/` directory into the container's Apache web server directory (`/var/www/html/`).

### **6. `COPY startup.sh /usr/local/bin/start.sh`**
- **Copy a custom script:** 
  - Copies a `startup.sh` script into the container’s `/usr/local/bin/start.sh` directory, which might contain additional setup commands.

### **7. `RUN chown -R www-data:www-data /var/www/html && chmod -R 775 /var/www/html && chmod +x /usr/local/bin/start.sh`**
- **Set file permissions:**
  - Changes ownership of `/var/www/html` to the Apache user (`www-data`).
  - Sets read, write, and execute permissions (`775`) for the web directory.
  - Makes the `start.sh` script executable.

### **8. `EXPOSE 80` and `EXPOSE 8080`**
- **Port exposure:** 
  - Exposes ports 80 and 8080 so the container can accept HTTP traffic. 
  - Port 80 is the default HTTP port; 8080 is commonly used for alternative web services.

### **9. `ENTRYPOINT ["apache2ctl", "-D", "FOREGROUND"]`**
- **Container entry point:** 
  - Specifies the command that runs when the container starts.
  - Launches Apache in the foreground mode to keep the container running.

### **Overall Function:**
This Dockerfile sets up an Ubuntu-based container with an Apache web server to serve a PHP-based website. It includes custom web content and a startup script, ensuring the environment is correctly configured. Apache is the core service that runs and hosts the website, handling HTTP requests on the exposed ports.

---

## Websocket
Next up is starting the websocket. The websocket is started by running the ```websocket.php``` located at ```/var/www/html```.
The command for running the websocket:

```php /var/www/html/websocket.php```

This needs to be run within the exec of the docker container you created.

---

If you need to get into a shell within the docker of the raspberry pi use this command:

```docker exec -it pi-little-endian-1 /bin/bash```

This command allows you to access an interactive shell inside a running Docker container. Let's break down what each part does:

1. **`docker exec`**  
   Runs a command inside an existing (running) container. This is useful for performing maintenance, debugging, or inspecting the container's state.

2. **`-it`**  
   These are two combined options:
   - **`-i` (interactive mode)**: Keeps the standard input (stdin) open, allowing you to interact with the container.
   - **`-t` (pseudo-TTY)**: Allocates a terminal for the session, making it behave like a typical command-line interface.

3. **`pi-little-endian-1`**  
   This is the **name or container ID** of the Docker container you want to access. In this case, it's called `pi-little-endian-1`.

4. **`/bin/bash`**  
   Specifies the command to run inside the container. Here, it opens a **Bash shell** (`/bin/bash`), providing a command-line interface within the container.

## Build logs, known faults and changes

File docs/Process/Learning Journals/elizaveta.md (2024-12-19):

Learning journal for elizaveta

---
sidebar_label: 'Elizaveta'
sidebar_position: 1
---

# Learning Story: Implementing the Fall Right Function and Mastering GitLab

## What needs to be learned
- How to implement servo control for robot movement.
- How to design a flexible function.
- How to use GitLab for version control, collaboration, and project management.

## What I've learned
In our robot dog project, one important functionality was making the dog fall to its right side. This task provided a great opportunity to enhance both my programming skills and my ability to collaborate using GitLab. I have gained some exeprience with embedded coding during this task.

### Step 1: Understanding Servo Control
The first step was understanding how to control servo motors with the ESP32Servo library. I learned that each servo motor's angle could be set from 0 to 180 degrees, allowing me to determine the necessary angles to position each leg for a controlled fall.

### Step 2: Designing the Function
I created the `fallRight` function, which accepts four Servo objects as references.

### Step 3: Testing
Using `Serial.println()` helped me track function execution,

## GitLab Workflow

### Step 1: Creating Issues
Before coding, I created an issue in our GitLab repository. The issue detailed the need for a "fall right" function. For issue I ahve creted accepatnce criterias and DoD.

### Step 2: Working with Branches
A new branch was created for this task. Working in a separate branch helped me isolate my changes from the main project.

### Step 3: Committing Changes
As I developed the `fall_right.h` file, I made commits with descriptive messages. I learned the importance of commit messages in maintaining an organized project history.

### Step 4: Creating a Merge Request
After completing and testing the feature, I created a merge request in GitLab. This process helped me present my changes to the team for review. I learned to write clear descriptions.

### Step 5: Code Review and Collaboration
Through the merge request, I received feedback from my team members. This experience showed me the benefits of peer review in catching potential issues, so the code can be improved or changed.

### Step 6: Merging and Closing the Issue
Once the changes were approved, I merged my branch into the main branch. I also learned to close the issue in GitLab.

## Conclusion
Implementing the `fall_right.h` file not only enhanced the functionality of our robot dog but also improved my embedded programming and GitLab collaboration skills.

# Learning Story: Creating a bitmap 

## What needs to be learned
- How to create a bitmap.
- How to use it in a code.
- How to use .

## What I've learned
I have learned how to 

### Step 1: Changing the size of the image 

I have found a nice picture from google, but it is needed to be resized, so the first thing I have done is found a simpe bitmap tool, so i can put new width and height.

### Step 2: Converting the bmf file into actual  

For the converting my file into the i was using some tools. 

### Step 3: Implementing my code into Header file    

## **Learning Question**
How can the PlatformIO extension in Visual Studio Code be utilized to test the robot dog’s components effectively?

## **Goal** 
The goal of this learning story is to understand how to use the PlatformIO extension in Visual Studio Code for assembling and testing a robot dog. The process involves setting up a PlatformIO project, putting code to control hardware components and testing.

## **Key steps of using the platform**
1. Install PlatformIO Extension: I have downloaded it from Extension section in VsCode.
2. Create a New Project: A new separate PlatformIO project was being created for the robot dog, we have copied and pasted src folder into the new folder. By creating a new project, it is possible  to specify and manage the required libraries.
I have learnt, that it is helpful to isolate my work from other projects. This isolation helps prevent conflicts between different sets of code and configurations, making it easier to manage and maintain the codebase.
3. Put the Code: i have put the code from the existing files i had for embedded part of the project.
4. Integrate Libraries: a few libraries were needed to be downloaded, so i just downloaded them straightly from "Libraries" section in PlatformIO.

## **Benefits of using the platform**
I have detected some benefits of using this extension:

Efficiency: PlatformIO automates many aspects of the development process, reducing the need for manual configuration and saving time.
Improved Debugging: With integrated debugging and a serial monitor, I can quickly detect and resolve issues with the robot dog's functionality.
Simplified Workflow: The PlatformIO extension streamlines the process of writing, testing, compiling, and uploading code, making the development cycle faster and more efficient.
Version Control: PlatformIO helps in maintaining and managing different versions of the firmware, enabling easy rollbacks and testing of changes.

## **Testing the Robot Dog with PlatformIO**

### **Step 1: Install Required Libraries**
To streamline development, all necessary libraries for the robot dog’s functionalities (e.g., ESP32Servo, Adafruit GFX, WiFiManager, ArduinoJson) were installed using the Libraries window in PlatformIO. This ensures that the code dependencies are managed effectively and automatically linked during compilation.

### **Step 2: Creating, compiling and uplading the code **

1. PlatformIO is being  used in Visual Studio Code to compile and upload the test script to  Arduino board. It can be done by clicking the "Upload" button in the PlatformIO toolbar or using the command palette. Printed messages can be observed in serial monitor.

### **Step 3: Example of testing the function **

#include <Arduino.h>
#include "movement/movement.h"

// Define the pins for the servos
const int flPin = 9;  // Front Left
const int frPin = 10; // Front Right
const int rlPin = 11; // Rear Left
const int rrPin = 12; // Rear Right

Movement robotMovement(flPin, frPin, rlPin, rrPin);

void setup() {
    Serial.begin(9600);
    robotMovement.initServos();
}

void loop() {
    Serial.println("Testing Walk Forward");
    robotMovement.walkForward();
    delay(2000);

    Serial.println("Testing Walk Backward");
    robotMovement.walkBackward();
    delay(2000);

    Serial.println("Stopping Servos");
    robotMovement.stopServos();
    delay(2000);
}

## ** Troubleshhoting **

If the servos do not behave as expected, the pin connections can be checked and ensure the servo library is correctly included and configured. 

# Learning Story: Creating a 3D Pyramid Face Using Laser Cutting

## Learning Question
I want to learn how to create a 3D face, which steps should be implemented and study the laser techniques.

So the first step, of course, is to come up with the plan of creating small tasks for every section.

## Tasks
1. **Research and Planning**
   - Study existing 3D pyramid designs and their applications.
   - Identify suitable materials for the face.
   - Review laser cutting techniques.

**Techniques**
1. Vector Cutting
- **What it is**: A process where the laser follows a path (vector line) to cut through the material completely.
- **Use Cases**: Creating shapes, parts, or intricate designs that need to be separated from the material.
- **Materials**: Wood, acrylic, cardboard, leather, and thin metals.
- **Tips**: 
  - Ensure lines in your design are hairline-thin for accurate cuts.
  - Optimize cutting paths to reduce time and material waste.
  - Use appropriate power and speed settings for clean edges.

2. Raster Engraving
- **What it is**: The laser scans back and forth (like a printer) to remove the surface of the material in a pattern or design.
- **Use Cases**: Adding details, logos, or decorative textures to the material’s surface.
- **Materials**: Wood, acrylic, leather, and coated metals.
- **Tips**:
  - Use high-resolution images for fine details.
  - Adjust power and speed to control the depth of engraving.
  - Test on scrap material to avoid overburning

3. Scoring
- **What it is**: A shallow cut into the surface without cutting all the way through.
- **Use Cases**: Adding fold lines, light decorative marks, or assembly guides.
- **Materials**: Paper, cardboard, and thin sheets of plastic or wood.
- **Tips**: 
  - Use lower power settings to avoid cutting through.
  - Score lines can help with precise bending or folding.

2. **Design**
   - Use CAD software (e.g., AutoCAD, Fusion 360) to create a 2D layout for the pyramid faces.
   - Include slots, tabs, or hinges for easy assembly.
   - Design space for securely mounting the OLED display inside the pyramid.

3. **Prototyping**
   - Create a cardboard prototype using the design.
   - Assemble the prototype to test fit and dimensions.
   - Adjust the design based on findings from the prototype.

4. **Assembly and Integration**
   - Assemble the laser-cut pyramid faces using glue or fasteners.
   - Mount the OLED display inside the pyramid.
   - Ensure visibility of facial expressions through the pyramid's opening.
   - Attach the pyramid face securely to the robot dog's head.

5. **Testing and Refinement**

- Test the assembled face for stability and fit on the robot.
   - Verify that the OLED display functions correctly within the pyramid.
   - Make any necessary adjustments to improve performance or aesthetics.

## Challenges and Solutions

Here are some probelms, a person may face, while working with lasercutting 

- Challenge: Ensuring the OLED display is visible through the pyramid structure.
  Solution: Experimented with different viewport designs and tested with various lighting conditions.

- Challenge: Achieving a secure assembly method for the pyramid faces.
  Solution: Tested different joining techniques (tabs and slots, hinges) to find the most stable configuration.

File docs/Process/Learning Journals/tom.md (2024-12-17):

# **Learning Journal |** Tom Jonker

## **Combining GitLab and Agile Workflow**
Since we're using GitLab to achieve an agile workflow, I was curious how we could this interface to increase our workflow. Most important here are the user of Epics, sub-epics and issues in combination with user stories. What do they mean and how can we use their full potential for our project?

### **Epics**
Epics aim to create a strategic view of a product or complex project, breaking it up into smaller manageable chunks. Breaking up a big, multifaceted project into smaller chunks allows for it to be easily digestible and for teams prioritize more important parts of a project, allowing them to allocate resources efficiently.

**Example:** `"Make a user authentication system."` or `"Create a Scratch-like code implementation."` 

### **Features**
Features function as 'sub-epics', dividing the Epic into even smaller chunks. The aim of a Feature is to create a functional chunk, making progress easier to track; key features can be created without the need to complete an entire Epic at once.

**Example:** `"Implement password Recovery"` or `"Develop login functionality"`

### **User Stories**
User Stories ensure features are built with the end-user’s needs in mind, avoiding overengineering or building unnecessary features. They serve as a 'Why' behind the work, promoting understanding between stakeholders and developers, and making it easier to estimateand deliver them witihin a sprint. 

User stories typically follow the format: ***"As a [user type], I want to [action], so that [benefit]."***

**Example:** `"As a user, I want to reset my password so that I can regain access if I forgot it."`

### **Issues (tasks)**
Issues fucntion as the executable task. Issues remove the ambiguity for developers, make progress visible and tangible by marking them as complete, and allowing Product Owners to identify blockers and dependencies early. By assigning a developer to an issue, responsility and ownership can be clarified.

**Example:** `"Desing the password recovery UI."` or `"Create and API endpoint for requesting password resets."`

<br>
Using these four components allows for an efficient, tangible and manageable Agile environment. Combining and Agile workflow with GitLab can be achieved by using GitLab's Planning functionality, allowing us to create Epics, Features and Issues and visualising them on a trello-like sprint board. Tags can be assigned to each issue, allowing the user to group tasks and assign priorities, visualising the priority of tasks.

<br>
<br>
<br>
<br>
<br>

## **Working with the 8-Point Grid**
Since no screen is the same, displaying the same website, application, dashboard or UI is difficult. The constant increase of pixel densities make the life of designers even more difficult.
Although all screens use different dimensions, popular displays all seem to be divisible by 8, making 8 a great standard for spacing.

The principle of 8pt Grid is that use multiples of 8 (8, 16, 24, 32, 40, 48, 56, etc.) to layout, dimensions, padding, and margin of elements.

### The value of the 8-point Grid

A Point (pt) is a measurement of space that depends on the resolution of a screen. When designing UI, a small artboard/frame is used, which is later upscaled to the required size. Designing on a smaller artboard allows the designer
to scale their assets on other screens easily, while maintaining pixel perfect rendering. Following a grid structure ensures the content of the website is scaled and rendered the same on all devices.

The 8pt grid ensures visual hierarchy to elements and drives consistent scalability, maintaining a 'quality of rythm' and creating a consistent look and feel.
Besides the improved design feel, it is also easier for designers to use in communication. A designer can recognize distances like 4px, 8px, 16px and 24px easily without measuring, as long as the 8pt grid system is used.

<figure markdown="span">
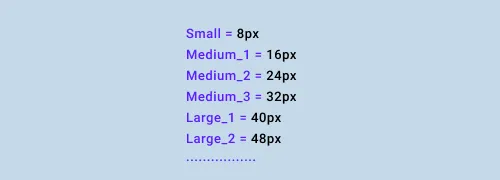
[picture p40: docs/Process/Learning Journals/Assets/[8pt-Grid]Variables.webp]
8pt Grid
    
    <figcaption>Figure 1: 8pt-grid in variables</figcaption>
</figure>

Using Figma as a design tool, variables and grid-layouts can be used to achieve better results. For example, as seen in Figure 1, variables can be made, each holding a larger value following the 8pt grid. This way, margins, paddings and other layout related variables don't have to be set manually, 
making the designing process more efficient and less prone to errors.

<figure markdown="span">
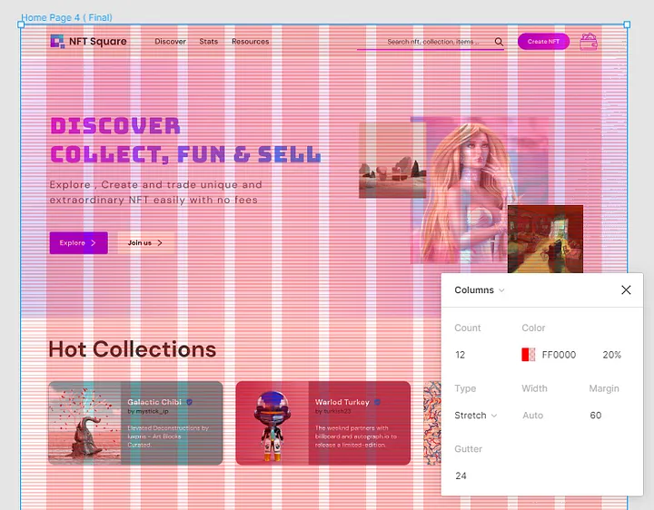
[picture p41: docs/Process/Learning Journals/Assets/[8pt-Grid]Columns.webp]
8pt Grid
    
    <figcaption>Figure 2: Using auto layout columns</figcaption>
</figure>

When working on websites you must make responsive web pages. The pages not only has to be displayed on a laptop, but also on smaller devices like phones and tablets. When we're talking about design rhythm, horizontal rhythm can be achieved by using a column grid. Again, using Figma as an example, 
a responsive column grid can be created, helping designers achieve horizontal rhtythm, improving their designs.

source: https://uxplanet.org/everything-you-should-know-about-8-point-grid-system-in-ux-design-b69cb945b18d

<br>
<br>
<br>
<br>
<br>

## **Creating a Solid and Modular Movement Code Architecture**

Since our project's main functionality is its movement, this part of the project must be solid and well thought through. This Submodule must be able to move the legs independently or simultaneously, working with preset and custom instructions. To achieve this result, we need to think about our approach.

### Leg abstraction

Before we start, let's consider the necessities of the movement structure. For now, we'll work with four servos, each functioning as a single leg. The most straightforward approach is to integrate the servos directly into our architecture, treating each servo as a single leg. However, this is subject to 
change since we're in our prototyping phase. Since our product will have four legs, we can create a wrapper for each leg, abstracting the physical sensors away. We can also bind some actions to this leg to further abstract the inner workings of the leg. If we're talking about actions, we could think about 
functions like `MoveLeg(angle, angle)`, independently controlling the lower and upper part of the leg independently. We could also take it a step further and create a `MoveLeg(X, Y)` function, utilizing an Inverse Kinematics approach to abstract the leg ultimately, but this may be outside our scope.

```cpp title="Leg.h"
class Leg {
public:
    Leg(int hipPin, int kneePin);
    void Attach();
    void MoveHip(int angle);
    void MoveKnee(int angle);
    void MoveLeg(int hipAngle, int kneeAngle);

private:
    Servo _servoHip, _servoKnee;
};
```

### Face abstraction

We could apply the same logic as we used to abstract the legs and apply it to the face. The face controls one or more OLED displays, but in the end, we only want to pass an image/bitmap to the face and make it display that particular face. We could also hardcode the bitmaps or store them somewhere, so we only 
have to pass an enum or something similar into the face, displaying the image on the OLED(s).

We take the first approach for now since it's more barebones, allowing us to expand upon it much more quickly. We extract the face from the main codebase and hide it between more straightforward functions.

```cpp title="Face.h"
class Face {
public:
    Face();
    ~Face();

    bool Initialize(int width, int height, int address, int rstPin = -1);
    void DisplayFace(int width, int height, const unsigned char* bitmap);

private:
    Adafruit_SSD1306* _display;
    int _width, _height;
};
```

### Creating the Movement

Finally, we can combine these two and create some movement and combine it with facial expressions. We could hardcode all the movements in the main file, but this would mean we can't use any custom code sent from the website, which is one of the project's primary goals. Instead, we'll create a movement structure, responsible for containing and running all the movement-related code.

```cpp title="Movement.h"
class Movement {
public:
    void addStep(std::function<void()> step) {
        steps.push_back(step);
    }

    void execute() {
        for (auto& step : steps) {
            step();
        }
    }
private:
    std::vector<std::function<void()>> steps;
};
```

Combining this, we can create code that's easy to maintain and expand. This particular implementation can also be used in combination with custom code since we can program the movements ourselves with the input from the website. This allows us to remove all the hard-coded code from the device and rely entirely on the website to provide movement and behavioral instructions.

```cpp title="main.cpp"
Movement walk;
walk.addStep([&]() { dog.MoveLeg(0, 45, 90); });  // Lift front-left leg
walk.addStep([&]() { dog.MoveLeg(1, 45, 90); });  // Lift front-right leg
walk.addStep([&]() { dog.MoveLeg(2, 45, 90); });  // Repeat for other legs
walk.execute();
```

<br>
<br>
<br>
<br>
<br>

## Creating a Manageable and Easily Navigatable Knowledge Base
To work efficiently and pass over knowledge easily, using a knowledge base is inevitable. Creating the knowledge base's content is a form of art, but creating an easily manageable and navigatable layout is a challenging task, too. Nothing is more frustrating than not finding what you're looking for. Besides, storing similar documents beside each other might increase the odds of opening another similar file out of curiosity and learning something new every day.

The goal of this research is to see if I can improve the layout of the portfolio website, changing it into an easy-to-navigate knowledge base.

### Sections
Storing the content in different sections can help us differentiate between files. Our project can be split up into three sections: Process, Device, and the Project. Inside the process, we store content related to our process, like meetings, conventions, and personal learning journals. The Device section will contain content about the device's inner workings and other related technologies. Finally, we create the Project page, which the user can visit to check out the manual, the setup, and the homepage of the project. Each section can be further split into smaller sections, each becoming more specific, allowing for easy navigation.

### Icons
To further improve clarity, we use icons. Icons help relate some text to certain functionality, but too many icons can be overwhelming and work against us; we have to use icons carefully. 
We could choose to use icons only in the first layer of our navigation bar, limiting the number of icons while still improving the overall navigation usability.

### Table of Contents
The final improvement is relatively simple but can help immensely with the overall look and clarity of the website: the Table of Contents. Currently, the Table of Contents is integrated into the navigation bar, amalgamating the ToC and the content of the navigation bar, making a massive mess of the navigation content. Instead, we could separate the ToC and show this functionality on the webpage. Moving the ToC helps us maintain clarity and improve the overall usefulness of the page and navigation.

<br>
<br>
<br>
<br>
<br>

## Improving DoD's to ensure the quality of our product

One of the most essential topics of working in an agile environment is the definition of done. This definition ensures quality in every contribution to the team, manages the project, and ensures nothing is forgotten.

Throughout the project, the definition of done might change due to certain circumstances, such as the addition of Code Conventions, a slight altercation to the scope, or a request from the stakeholders. Our project experienced some of these changes, causing us to look back at our DoDs.

### Consistency
We're currently using four templates: one for user story issues, one for learning story issues, one for merge requests regarding user stories, and one for merge requests regarding learning stories. One notable issue is the lack of consistency throughout these templates. There is a lack of capitalization, interpunction, and inconsistency in list types; some use bullet points, and others use a checklist. 

### Specific DoDs
Since we adopted new methods of ensuring quality besides the DoD, we need to ensure these methods are used before merging the created code into the main codebase. To ensure this, we create more specific versions of these definitions and place them under an "If applicable" tab. We can check these boxes if they're applicable to the work that is submitted and show that the methods are used.

Applying these two changes helps us ensure the quality of our project and may prevent future errors and bottlenecks due to low-quality code.

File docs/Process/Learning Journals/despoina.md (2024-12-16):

### Learning Story [#119]: Making Database Changes Visible to Team Members

How can I set up and share a database online so my team can use it securely without any issues?

1. Verify Permissions
Ensure that all team members have the correct database permissions.

    1. Log in to the database as an admin.
    2. Check user privileges for the database in phpMyAdmin:  
    ``
    SHOW GRANTS FOR 'username'@'host';
    ``
    3. Ensure they have at least SELECT and INSERT privileges for the new tables.  
    ``
    GRANT SELECT, INSERT ON database_name.* TO 'username'@'host';
    FLUSH PRIVILEGES;
    `` 

2. Ensure Database is Properly Shared  
Check the docker-compose.yml file to confirm:

    - The database service is correctly configured with shared volumes to persist changes.  
    - Example configuration for shared volume:  

    ``
    services:  
    db:  
        image: mariadb  
        environment:  
        MYSQL_DATABASE: my_first_robot  
        volumes:  
        - ./db_data:/var/lib/mysql
    ``

    - The db_data directory ensures all changes, including new tables, are saved and shared.

### Learning Story [#120]: Implementing a MariaDB Database with Docker Compose

How can I create and configure a MariaDB database using Docker Compose to ensure it is easily deployed and accessible for all team members?

1. Setting Up the Docker Compose File: We have configured a Docker Compose file that defines a MariaDB container along with necessary environment variables. This setup allows anyone in the team to easily spin up a consistent MariaDB database environment.

    docker-compose.yml:
    ``
    version: '3.1'

    services:
    db:
        image: mariadb:latest
        container_name: mariadb_container
        environment:
        MYSQL_ROOT_PASSWORD: ${MYSQL_ROOT_PASSWORD}
        MYSQL_DATABASE: ${MYSQL_DATABASE}
        MYSQL_USER: ${MYSQL_USER}
        MYSQL_PASSWORD: ${MYSQL_PASSWORD}
        ports:
        - "3306:3306"
        volumes:
        - mariadb_data:/var/lib/mysql

    volumes:
    mariadb_data:
    ``

    **Explanation:**

    - image: mariadb:latest: This uses the latest official MariaDB image.    
    - container_name: mariadb_container: The container will be named mariadb_container.  
    - environment: Here we define important environment variables like the root password, database name, and user credentials. These credentials are stored in a .env file to keep sensitive information safe.  
    - ports: "3306:3306": This exposes the database on the host machine's port 3306.  
    - volumes: mariadb_data:/var/lib/mysql: This ensures that the database data is persisted across container restarts.

2. Configuring .env file  
    The .env file contains the sensitive environment variables used in the Docker Compose file. It keeps the credentials and database name secure.

    ````
    MYSQL_ROOT_PASSWORD=  
    MYSQL_DATABASE=  
    MYSQL_USER=  
    MYSQL_PASSWORD=  
    ````

3. After setting up the Docker Compose file and .env file, start the MariaDB container:

    ``
    docker-compose up -d
    ``

    This command will pull the MariaDB image and start the database container in the background.

4. Access PhpMyAdmin:  
PhpMyAdmin can be accessed through the web browser at http://localhost:8081. Use the MYSQL_USER and PMA_PASSWORD from the .env file to log in.

### User Story [#129]: Sharing database tables and data via docker-compose.yml
In order to address some of the issues I encountered during the development process, I decided to implement a solution that would ensure persistence of data in MariaDB when using Docker. Initially, I faced challenges with maintaining the database content across container restarts, as well as managing large commits due to changes in the MariaDB data files. Through researching for my learning story, I found an effective solution using Docker volumes and initialization scripts.

1. Data storage Issue:  
Previously, whenever I stopped or deleted the Docker container, I would lose all the data stored in the MariaDB database. To resolve this, I implemented a solution by creating a data folder named mariadb_data. This folder is used to store all the necessary SQL files and data needed by MariaDB. By using a Docker volume, I ensured that data stored in mariadb_data persists even when the container is deleted or rebuilt.

To verify that it works, I tested it by deleting the container, initializing it again, and rebuilding the Docker service. I confirmed that all the rows inserted into the database remained intact, and the tables were still available.

2. Git Commit Issue:  
While trying to commit my changes, I realized that over 200 changes were being tracked by Git, most of which were related to the MariaDB data files. This wasn’t ideal, as it would result in an unnecessary bloated commit history. To resolve this, I needed a way to avoid tracking these large data files in Git while still making sure that the necessary schema and database setup were shared with my teammates.

The solution was to use a .gitignore file to exclude the mariadb_data folder from version control. By doing this, the database data files wouldn’t be included in commits, yet I could still share the database structure and initialization scripts.

3. Creating Initialization Script:  
Since the database tables needed to be created and initialized every time the container starts, I created an init-scripts folder to store SQL files like schema.sql. These files define the structure of the database and the tables, including the robots table, which tracks information such as the robot's ID, UUID, name, and uptime.

I then updated the docker-compose.yml file to automatically run these initialization scripts when the MariaDB container starts. By mapping the init-scripts folder to /docker-entrypoint-initdb.d in the container, Docker will automatically execute the SQL files in this directory upon initialization. This ensures that the database is correctly set up each time the container is started.

The change is located in the volumes part of mariadb in the docker-compose.yml file:
````
mariadb:
    image: mariadb:latest
    container_name: mariadb_container
    restart: always
    environment:
      MYSQL_ROOT_PASSWORD: ${MYSQL_ROOT_PASSWORD}
      MYSQL_DATABASE: ${MYSQL_DATABASE}
      MYSQL_USER: ${MYSQL_USER}
      MYSQL_PASSWORD: ${MYSQL_PASSWORD}
    ports:
      - "3306:3306"
    volumes:
      - ./mariadb_data:/var/lib/mysql
      - ./init-scripts:/docker-entrypoint-initdb.d
````

This setup ensures that the MariaDB container will use the SQL files located in the init-scripts folder to initialize the database when it starts.

4. Testing  
After implementing the changes, I verified that everything was working correctly. I stopped and restarted the containers multiple times to confirm that the data was still there after the restarts. I also tested the database intitaization by ensuring that the robots zable was created properly with the correct structure and that the intitial data was inserted successfully.

### Learning Story [#138]: C++ Coding Conventions Research  
To address challenges in organizing and maintaining clean code for the robot dog’s functionalities, I researched and implemented C++ coding conventions. My primary goal was to create a codebase that adhered to industry standards, ensuring it was modular, readable, and easy to maintain. By referring to the Google C++ Style Guide, I identified and adopted key practices to improve the quality of our code.

This process also helped me with teamwork and allowed me to follow coherent coding connventions when collaborating.

1. Readability and Maintainability  
One of the first issues I noticed was the lack of a consistent style throughout the project. Variable names, function structures, and file organization varied widely because different team members followed their own conventions. This made it difficult for anyone other than the original author to read or debug the code.

After studying the Google C++ Style Guide, I adopted the following conventions:

- File naming: Use CamelCase for filenames (e.g., Face.cpp, Face.h)  
- Variable naming: Use lowerCamelCase for variable names (e.g., isConnected)
- Function Naming: Use lowerCamelCase for function names (e.g., moveForward())  
- Class Naming: Use CamelCase for class names (e.g. RobotDog)

By implementing these naming conventions, I achieved better consistency and improved code readability, which was particularly helpful in a group setting.

2. Using Classes  
A recurring issue was inconsistent use of object-oriented programming. Some group members used classes effectively, encapsulating data and methods, while others preferred standalone functions in header files. This inconsistency caused confusion about how to organize the code.

To address this, we standardized the use of classes:

- Encapsulate functionality into classes: For example, a Leg class would handle all methods related to leg movements (e.g., moveForward(), sit()), while a Head class would handle head-specific actions.
- Separate files for class implementation: Each class has a .cpp file for implementation and a corresponding .h file for declarations.

This structure ensures that the code remains modular and scalable as we add new features to the robot dog.

3. Code redundancy  
Another issue we had to ensure we do not do was code redundancy. Without proper organization, different team members could write the same functionality multiple times in different parts of the codebase. This redundancy not only wastes time but also makes the code harder to maintain.

To combat this, we agreed to:

- Create reusable methods in separate files: For example, instead of rewriting the same walking logic in multiple places, we created a single Walking class with reusable methods.  
- Leverage header files for shared functionality: These header files act as a central source, ensuring consistency and reducing duplicate code.

Coding conventions for developing with C++ are also shared with the team and can be found in the cpp.md file.

**Sources**

- [Google C++ Style Guide](https://google.github.io/styleguide/cppguide.html)

### Learning Story [#140]: Assembling Robot Dog
How can I assemble the robot dog together, in order to make it functioning?  
To answer this answer, I followed the assembly guide of the previous team and moved on on assembling the robot dog. These are the steps that are to be followed:

1. **Attach Risers**  
   Use 3 risers (2.4x16mm) and bolts to secure them to the top plate. These will hold the protoboard.

2. **Attach Sides**  
   Fix the sides to the bottom baseplate. The square hole is for the front servo, and the round hole is for the back servo.

3. **Install Servos**  
   Insert 4 SG90 mini servos into the holes on the side plates. They should fit snugly.

4. **Place Baseplate Connectors**  
   Insert the connectors into the slots on the bottom plate to hold the servos and connect the plates.

5. **Fit the Top Plate**  
   Attach the top plate over the baseplate connectors and sides. Ensure everything aligns tightly.

6. **Secure with Bolts**  
   Use 3.9mm bolts to fasten the top and bottom plates. Tighten gently to avoid cracking the plexiglass.

7. **Attach Legs**  
   Turn the robot dog upside down and use a screwdriver to secure the legs to the servos. Ensure the servos move with the legs.

8. **Add Face Mount**  
   Slot the face mount into the slit at the front of the robot dog.

9. **Mount Protoboard**  
   Attach the protoboard to the risers on the top plate. This will hold the ESP32 and connections.

10. **Place Power Supply**  
    Insert a 9V battery into the slot on the bottom plate. Connect it last to avoid turning the robot on prematurely.

11. **Stick Breadboard**  
    Place the breadboard on the top plate between the battery and face mount. Stick it after trying out its placement.

12. **Install OLED Display**  
    Secure the OLED display to the face mount using bolts and nuts. This will display the robot's emotions.

13. **Connect ESP32 & Wiring**  
    Attach the ESP32 to the protoboard and connect the servos, power supply, and OLED display. Match servo wires (brown to black) and ensure proper placement on the protoboard.  

The robot dog I took up on had already its body assembled, so I continued with the remaining necessary steps.

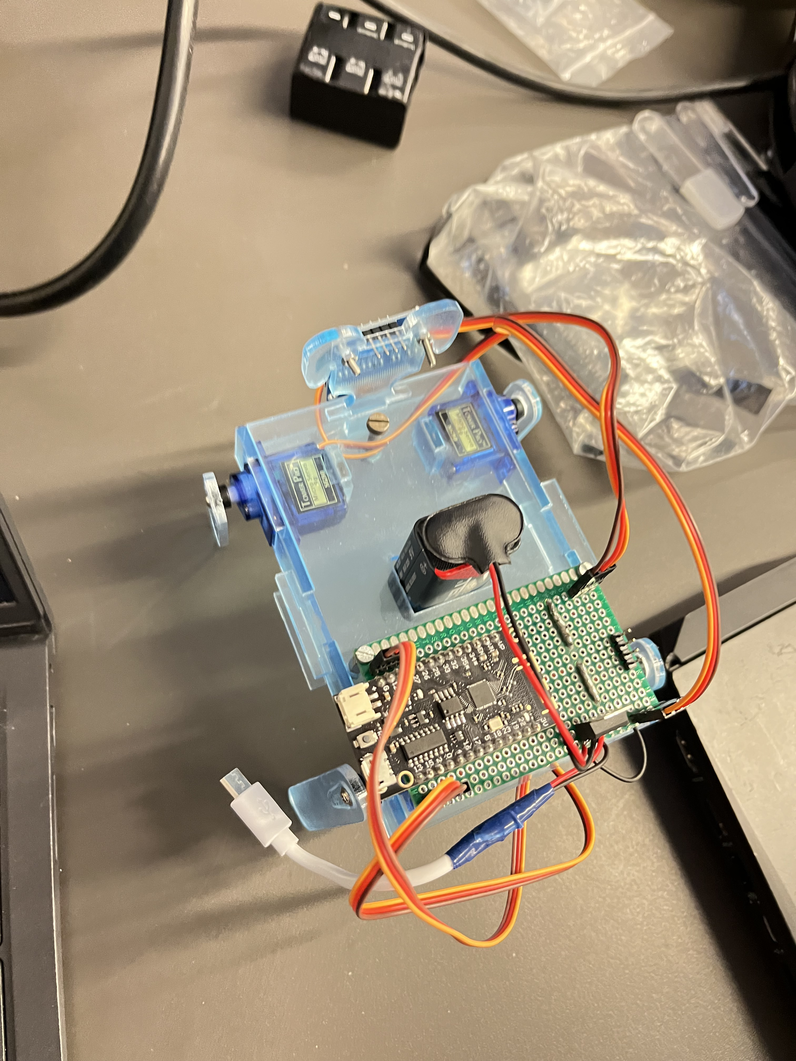
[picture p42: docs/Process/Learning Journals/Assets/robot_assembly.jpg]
Robot Dog Assembly


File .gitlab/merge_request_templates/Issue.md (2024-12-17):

# Description

<!-- Add description -->

# Acceptance Criteria

<!-- Add Acceptance Criteria -->

# Definition of Done

## Documentation
- [ ] Work is documented in standard English.
- [ ] Work is documented so that it can be used by the user (End user documentation).
- [ ] Work is documented so that it can be used by the developer (Technical documentation).
- [ ] Used sources are referenced where used.

## Quality
- [ ] Work is committed to git via a merge request.
- [ ] Work is peer reviewed.

## Specific (if applicable)
- [ ] Work follows coding conventions stated in the knowledge base.
- [ ] Work follows the AUAS/HvA HouseStyle, stated in the knowledge base
- [ ] Work is linted and throws no errors.
- [ ] Work is tested and works.
- [ ] Responsiveness is checked in Chrome Devtools or a similiar tool. (Chrome Devtools: Mobile S, Mobile M, and Mobile L)

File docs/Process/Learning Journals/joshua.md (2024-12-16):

Learning journal for joshua

# Tuesday 26th November 2024

Today I'm going to work on one or two userstories,
First I'm going to create a button that will allow the user to wag the tail of the dog
and secondly I'm going to work on the embedded part and rewrite some of the code to make it more efficient and readable.

Update:

I created a button in the frontend and rewrote some code in the embedded part of the device, I also used the ip constant
instead of hardcoded ip's

# Friday December 13 2024

Today I'm going to work on documentation for both my userstory and learning story, and then after that I will pick up another userstory, and I will create a learning story for linting so that we can be consistent with conventions in our project.

#### Documentation for learning story #136

I researched google code conventions and created files for the main conventions we're going to use, as a formal question I have "What code conventions can we use as a team?" So as a team we decided to use the google code conventions. More specifically mentioned in the files `Web Conventions.md` In there I also have the link to the code conventions of google. 

The sources that I used for this learning story are as follows:

[Javascript Code conventions](https://google.github.io/styleguide/jsguide.html)

[HTML & CSS Code conventions](https://google.github.io/styleguide/htmlcssguide.html#HTML_Style_Rules)

#### Elaboration on Research
The reason I researched the google code conventions that are mentioned in the convention files is to ensure that our team follows consistent coding standards.
The main findings from my research include best practices for writing clean, readable, and maintainable code in JavaScript, HTML, and CSS. These conventions cover different parts such as naming conventions, code formatting, and documentation standards.

#### Findings

- **Javascript**: Emphasis on using `const` and `let` instead of `var`, preferring arrow functions, and following a consistent naming convention.
- **HTML & CSS**:  Guidelines for structuring HTML documents, using semantic tags, and maintaining a consistent style for CSS selectors and properties.

#### Enforcing

To ensure that these conventions are followed, we as a team will work on implementing the following measures.

- **Code reviews**: Regular code reviews will be conducted with merge requests.
- **Linting Tools**: We will try to implement Linting tools such as `ESLint` for JAvascript and `stylelint` for CSS.
- **Documentation**: The `Web Conventions.md` file will serve as a reference for all team members, providing detailed guidelines and examples.

By implementing these measures we will try to maintain high code quality and consistency as a team across our project.

# Sunday December 15 2024

#### Learning Question

Why is implementing a linter good for our project and is it worth the time?

To answer this question I will first look at why a linter would be benefinicial for our current project.

**Benefits**

1. **Consistency**: It ensures code conventions are followed and are consistent across the entire codebase.
2. **Error Detection**: Less inconsistency means Less errors, it also helps catch syntax errors and potential bugs early in the development process.
3. **Code Quality**: It enforces the best practices and coding standards for everyone in the group, which means that it leads to higher quality code.
4. **Productivity**: It saves time by automatically checking for common issues that are known
5. **Maintainability**: And finally atlast, it makes the code easier to read and maintain by keeping a consistent style

Overall, the time that is invested in setting up and using a linter is typically worth it because of the benefits of the better and more consistent code quality and reduced debugging time.

**Which linters will we use for our project?**

Because we're using the google coding conventions, and because we have HTML, CSS and Javascript files, we are going to use the following linters:

1. **HTML**: [HTMLHint](https://htmlhint.com/)
2. **CSS**: [Stylelint](https://stylelint.io/)
3. **JavaScript**: [ESLint](https://eslint.org/)

These linters are widely used and have extensive documentation and community support. They can be easily configured to use the google coding standards that we will apply to our project which is why we will be using these.

**How Will we configure these for the google coding standards?**

Originally these linteres do not use google coding standards by default. However, we can easily configure them to use these standards.

For `ESLint(Javascript)` we will the command `npm install eslint-config-google` and then in the `.eslintrc` config file we could use a simple `"extends": "google"` to configure ESLint to use the google coding standards.

For `Stylelint(CSS)` we will use the command `npm install stylelint-config-google` then the same as our ESLint file, in the `.stylelintrc` config file we use `"extends": "google"` to use the google standards for CSS.

For `HTMLHint(HTML)` there is no official google style config, but we can manually configure the most important rules in the `.htmlhintrc` file to match Google's HTML conventions.

So in short, **is it worth it to implement a linter?** Yes, the benefits heavily outweigh the time it takes to put this up, it will help everyone be more consistent, reduce debugging time and improve code quality.

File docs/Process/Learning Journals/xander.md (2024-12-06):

# **Learning Journal |** Xander Tamis

## Learning Story [#122]: C++ Header Files and their benefits and drawbacks

To avoid having one large bloated main file with every function in it, we want to use header files to contain the separate functions. But what exactly are header files, what benefits and drawbacks do they have and what are their use cases?

### Header files

Header files allow developers to put their declarations in one place and then import them wherever necessary.

They usually have a <code>.h</code> extension, but there are also header files with a <code>.hpp</code> extension or no extension at all.

The content of a header file is inserted at the point of inclusion. That means that if a function calls on data from a header file before the header file is inserted, then the function won't be able to access the data.

If you use a function multiple times across several files, then any change would require you to go through all those files and change the function everywhere. 

By using a function file to contain the function in combination with a header file to contain the declarations, you can simply include these two files in every file that you want to access the function and then you only need to change these two files to have it change everywhere.

### Example

If you have a function <code> add() </code> that you want to access in multiple files, you could create a function and header file for it.

The header file: <code>add.h</code> would look like this:

```
int add(int x, int y);
```

The function file: <code>add.cpp</code> could look something like this:

```
#include "add.h"

int add(int x, int y) {
    return x + y;
}
```

And then in <code>main.cpp</code> you can have it as follows:

```
#include "add.h"
#include <iostream>

int main() {
    std::cout << "The sum of 3 and 4 is " << add(3, 4) << '\n';
    return 0;
}
```

Without a header file, you would have to include the declaration for the function file in every file where you'd wnat to use the function like in the code example below:

```
int add(int x, int y);

int main() {
    std::cout << "The sum of 3 and 4 is " << add(3, 4) << '\n';
    return 0;
}
```

This is not a big deal when you only have a few declarations, but can get annoying quickly when dealing with a lot of declarations that need to be written down in every file.

### Upsides

- Code Organization:
Header files help separate interface from implementation, making code easier to manage.

- Reusability:
Once written, a header file can be included in multiple source files.

- Ease of Collaboration:
In larger projects, header files allow team members to work independently on different parts of the program by clearly defining the interface between modules.

### Downsides

- Increased Compilation Time:
If headers are large or include other headers, it can lead to longer compilation times due to repeated processing of the same headers for each source file.

- Easier to create circular dependencies: Poorly designed header files can lead to circular dependencies, leading to compilation errors.

- Overuse: Using too many headers can lead to unnecessarily complex codebases. 

### Sources

https://www.learncpp.com/cpp-tutorial/header-files/

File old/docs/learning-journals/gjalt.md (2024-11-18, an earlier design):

# Learning journal Gjalt

## communication between robot and webserver

**Research Documentation: communication between robot and webserver**

**Research Question:**  
As a student, I want to know if a tunnel is usable for communication between webserver and our robot.

**Approach:**  
We developed a straightforward program in Python to illustrate how this communication setup could function. The program utilized sockets for establishing the connection and JSON for structuring the data exchanged between the web server and the robot.

**Key Components:**

1. **Socket Communication:**  
   Our program created a pathway, like a tunnel, for the web server and the robot to communicate. This pathway, known as a socket, allowed them to exchange messages seamlessly.

2. **Data Serialization with JSON:**  
   To send information from the web server to the robot, we formatted it using JSON. JSON helped organize the data in a way that both the server and the robot could understand easily.

3. **Usage Demonstration:**  
   We demonstrated the functionality of our program by running it. It acted as the server, waiting for the robot to connect. Once connected, it solicited instructions (such as how much to turn) and transmitted them to the robot through the established tunnel.

**Using the Program:**

1. **Setting Up the Server:**  
   - We initiated the program, simulating a server awaiting the robot's connection. It listened for connections on a designated address and port, much like waiting for a call on a specific phone line.

2. **Sending and Receiving Data:**  
   - When the robot connected, the program requested instructions, like how far to turn. These instructions were formatted as JSON and sent to the robot through the tunnel.

3. **Ending the Connection:**  
   - To conclude the communication, we simply typed 'exit', prompting the program to gracefully close the connection.

**Conclusion:**  
Our program demonstrated how communication between a web server and a robot could be established using sockets and JSON. While it served as a basic example, it illustrated the effectiveness of tunnel-based communication. Additionally, it showcased the potential for integration with Arduino code, paving the way for practical implementations in robotics projects.

## protoboard making

The connections on a protoboard with loose is not optimal and causes strange behavior from the robot because some connection can come loose while moving.

so i went to the circulation desk to get a protoboard and started thinking bout how to construct this specifically for our robot. and asked some colleges what i needed here is a quick partslist:

Parts list:
- Protoboard (Can be any size because you can make is smaller with a saw) 
- header risers (for plugging the esp in to the protoboard)
- normal header pins (For plugging the connectors in for the servo's)

When i collected the parts i immediately started wiring the power and ground. after that i decided which pins we where going to use to transfer the data for the servos these are 5, 16, 17, 18.

My college made some pictures of me making the first board. here are the pcitures he made:





when all the soldering was done this was the end result:

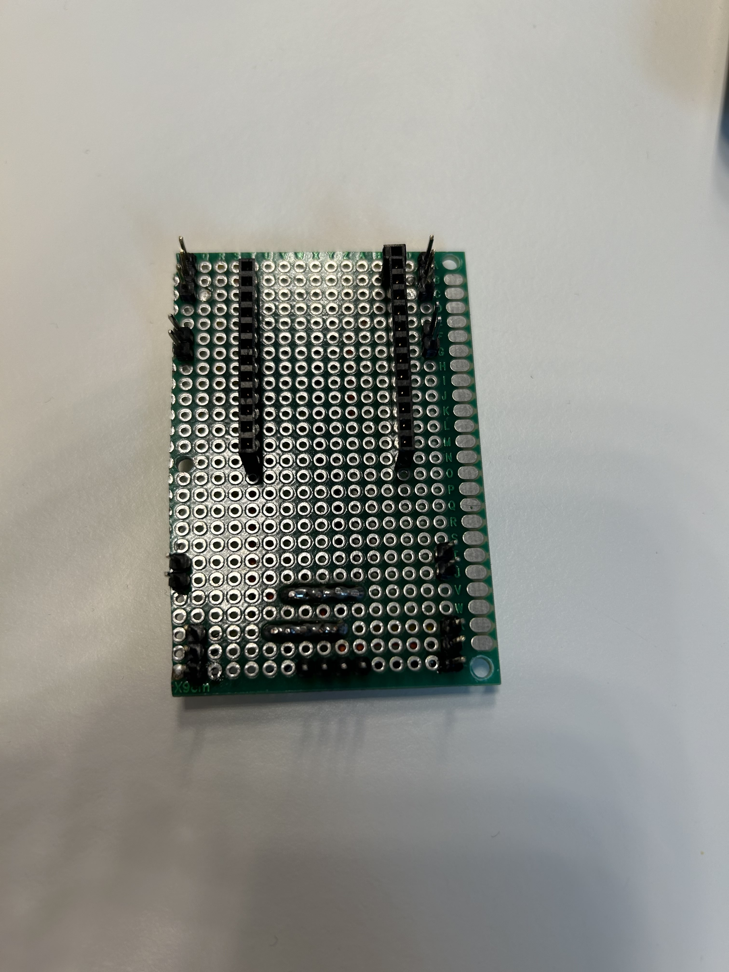
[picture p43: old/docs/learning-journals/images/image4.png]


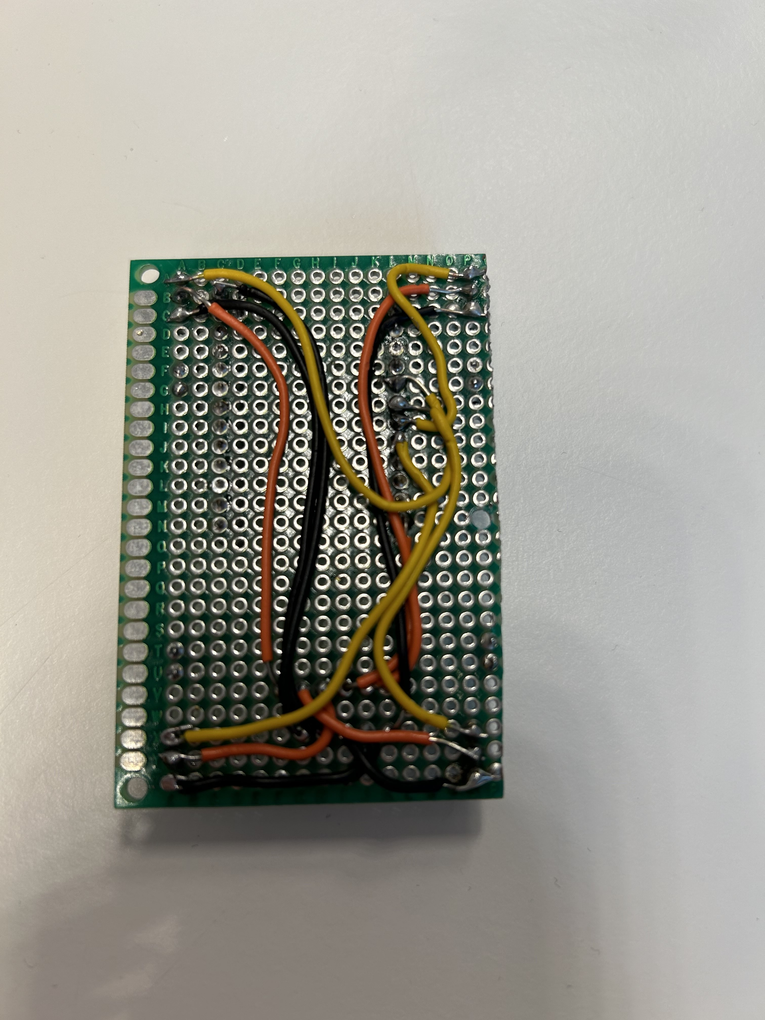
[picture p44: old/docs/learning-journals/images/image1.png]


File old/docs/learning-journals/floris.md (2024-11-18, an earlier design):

# Learning journal

## Research story: As a student, i want to research blockly so that i can look if theres a better way to program the code blocks
In order to program the robot, gerald has requested to have a full interface that works well with if statements and more complex blocks, thats why i have decided to look into blockly.

Blockly looks simple and easy to add blocks to, i first looked into the tutprial on the blockly website itself but i struggled with that. Using chatGPT i have found a better explanation. Using chatGPT has helped a lot here.

## Research story: As a student, I want to research the best way to have the robot excecute live code from a string
IN order to have the robot excecute live code, we need to send it and have it interpreted, theres 2 ways to do this from what ive found.
C++ is a very bad language for interpreting live code like this from a string, so it cant really be sent to the arduino and have it interpreted there, unless:
#### Method 1, build a code interpreter
This could be very hard but doable, you would translate every line to a command and if theres a logic line, you would translate that aswell. Like with an if statement you could make a variable, check the if statement for the contents and excecute the code in between the {}. This is very time consuming and could be way too hard, also hard to add more features.
#### Method 2, interpret in javascript
From what ive found in javascript its way easier to interpret all the code and have it excecuted live, this method does however make it so that the robot isnt really doing it autonomous. Instead the phone or laptop is still making it so that the robot moves, its sends the commands line for line and not the intire program. You do need to be connected the robot at all times.

# Endian A
this is the endian A design

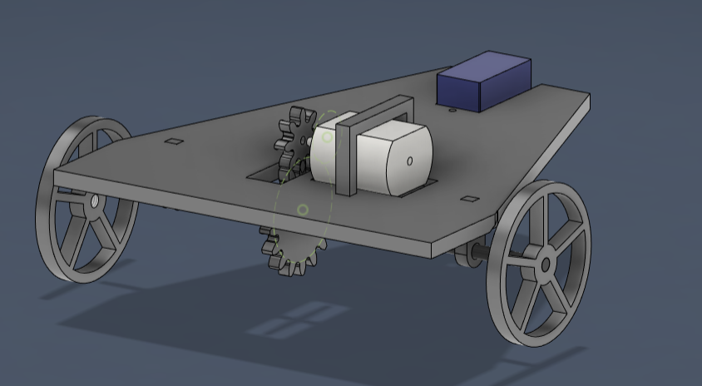
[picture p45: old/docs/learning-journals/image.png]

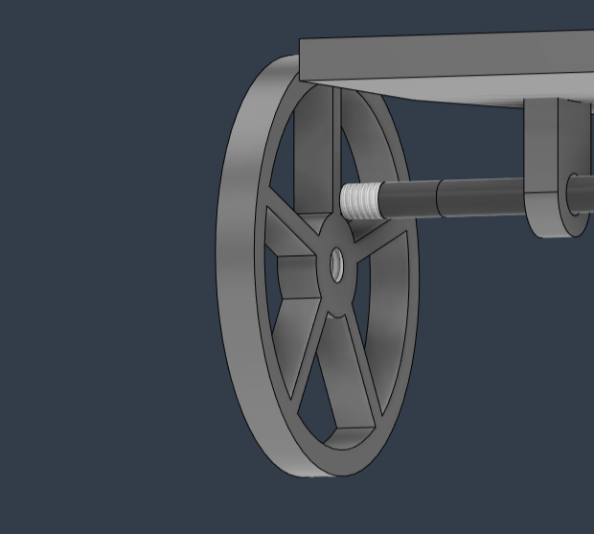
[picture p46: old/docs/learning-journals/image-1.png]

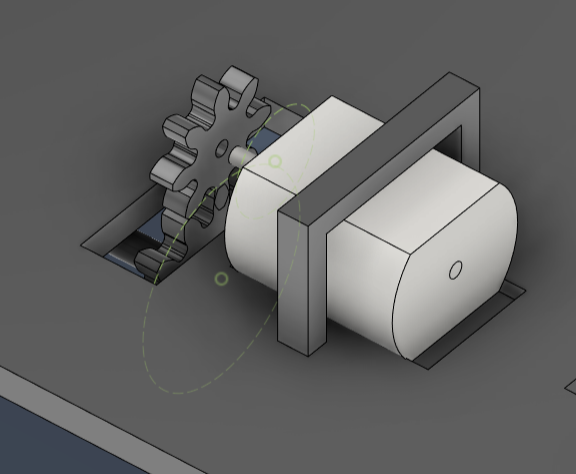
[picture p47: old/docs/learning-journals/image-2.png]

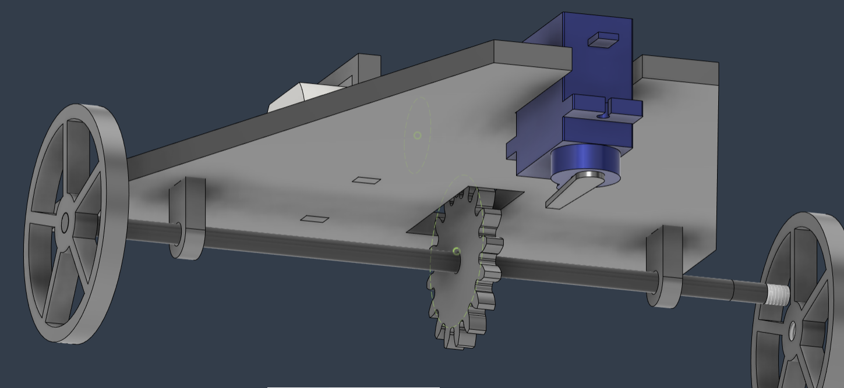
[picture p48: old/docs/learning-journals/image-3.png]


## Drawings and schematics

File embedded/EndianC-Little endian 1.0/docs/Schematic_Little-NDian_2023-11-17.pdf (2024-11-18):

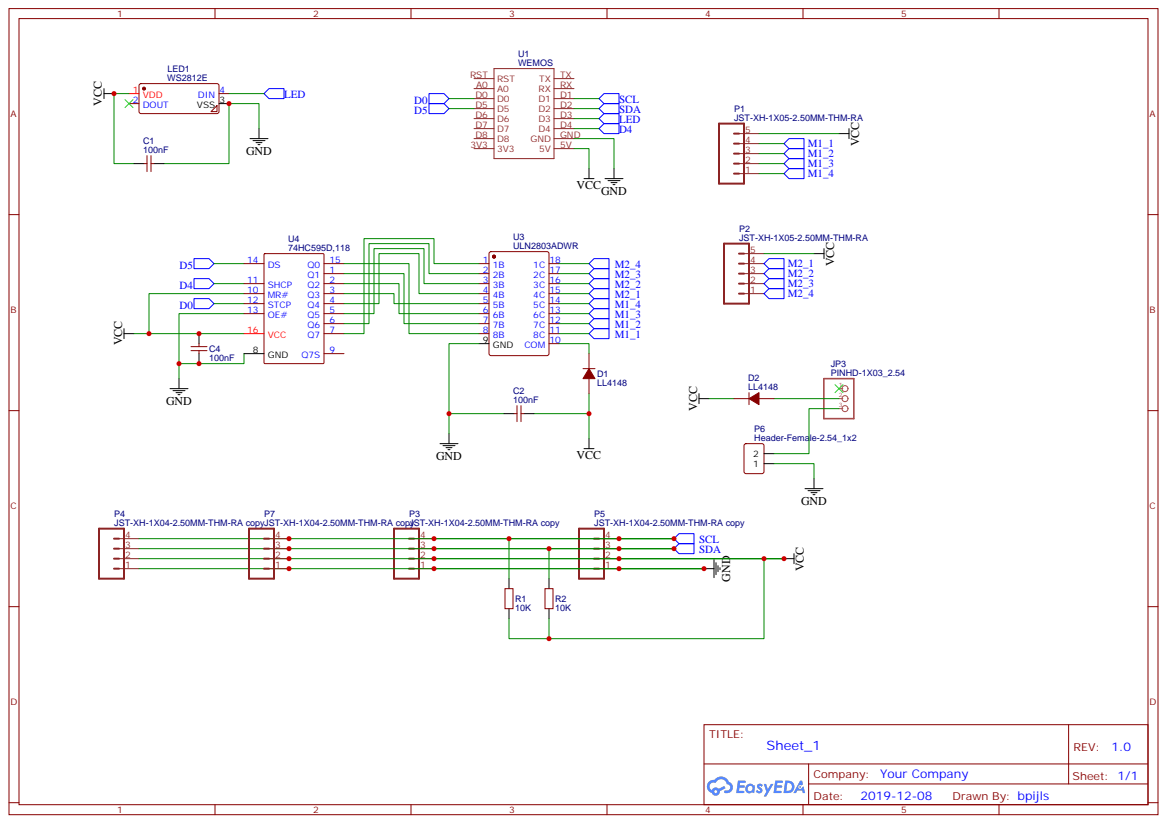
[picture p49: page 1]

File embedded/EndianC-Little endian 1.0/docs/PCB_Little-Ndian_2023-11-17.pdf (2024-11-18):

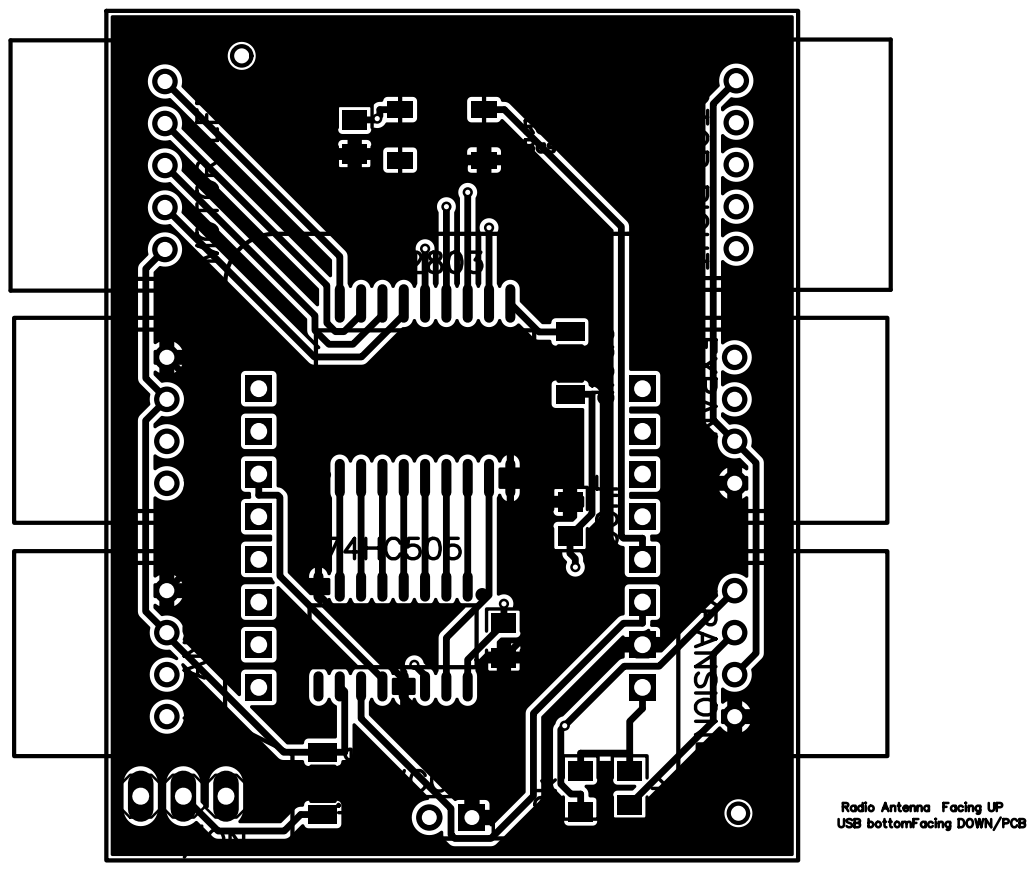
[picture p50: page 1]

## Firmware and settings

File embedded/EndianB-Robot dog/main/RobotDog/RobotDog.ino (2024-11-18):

\#include <ESP32Servo.h>
#include <WiFiManager.h>
#include <WiFiClient.h>
#include <ArduinoJson.h>

// WiFi and server details
const char* server_ip = "172.20.10.5";
const uint16_t server_port = 1234;

WiFiClient client;
bool isConnected = false;

// Define the pins for the servos
#define SERVO_FL_PIN 4
#define SERVO_RL_PIN 16
#define SERVO_FR_PIN 17
#define SERVO_RR_PIN 5

#define DEFAULT_POS 90
#define WALK_OFFSET 30
#define WALK_DELAY 350

// Preset for Sitting
#define DEFAULT_FL_SIT 110
#define DEFAULT_FR_SIT 70
#define DEFAULT_RL_SIT 35
#define DEFAULT_RR_SIT 145

// Preset for lying down
#define PRESET_FL_LIE 0
#define PRESET_FR_LIE 180
#define PRESET_RL_LIE 180
#define PRESET_RR_LIE 0

// Wave preset
#define WAVE_DOWN 30
#define WAVE_UP 0

// Turning presets
#define TURN_RIGHT_FL 60
#define TURN_RIGHT_FR 120
#define TURN_RIGHT_RL 120
#define TURN_RIGHT_RR 60

#define TURN_LEFT_FL 120
#define TURN_LEFT_FR 60
#define TURN_LEFT_RL 60
#define TURN_LEFT_RR 120

// Create servo objects
Servo FL; // Front left leg
Servo FR; // Front right leg
Servo RL; // Rear left leg
Servo RR; // Rear right leg

String currentCommand = "";
String currentValue = "";

void setup() {
  Serial.begin(115200);
  // Attach servos to pins
  FL.attach(SERVO_FL_PIN);
  FR.attach(SERVO_FR_PIN);
  RL.attach(SERVO_RL_PIN);
  RR.attach(SERVO_RR_PIN);
  // Move servos to initial position
  moveToStartPosition();

  // Initialize WiFiManager
  WiFiManager wifiManager;

  // Uncomment the line below if you want to reset settings
  // wifiManager.resetSettings();

  // Start WiFiManager
  // if (!wifiManager.autoConnect("Robot Dog")) {
  //   Serial.println("Failed to connect to WiFi");
  //   ESP.restart(); // Reset if WiFiManager fails to connect
  // }
  // Serial.println("Connected to WiFi");

  delay(3000);
}

void walkForward() {
  unsigned long startTime = millis();
  
  while (currentCommand == "forward" && millis() - startTime < 5000) { // 5 seconds
    RL.write(DEFAULT_POS + WALK_OFFSET);
    delay(100);
    FL.write(DEFAULT_POS - WALK_OFFSET);

    FR.write(DEFAULT_POS - WALK_OFFSET);
    delay(100);
    RR.write(DEFAULT_POS + WALK_OFFSET);

    // Delay
    delay(WALK_DELAY);

    FL.write(DEFAULT_POS + WALK_OFFSET);
    delay(100);
    RL.write(DEFAULT_POS - WALK_OFFSET);
    
    RR.write(DEFAULT_POS - WALK_OFFSET);
    delay(100);
    FR.write(DEFAULT_POS + WALK_OFFSET);

    // Delay
    delay(WALK_DELAY);
  }

  // Stop the movement
  moveToStartPosition();
}

void moveToStartPosition() {
    FL.write(DEFAULT_POS);
    FR.write(DEFAULT_POS);
    RL.write(DEFAULT_POS);
    RR.write(DEFAULT_POS);
    delay(50);
}

void lieDown() {
  Serial.println("Lying down");
  FL.write(PRESET_FL_LIE);    // Move front left leg to lying position
  FR.write(PRESET_FR_LIE);  // Move front right leg to lying position
  RL.write(PRESET_RL_LIE);  // Move rear left leg to lying position
  RR.write(PRESET_RR_LIE);    // Move rear right leg to lying position
}

void sit() {
  Serial.println("Sitting down");
  FL.write(DEFAULT_FL_SIT);   // Front legs stand
  FR.write(DEFAULT_FR_SIT); 
  RL.write(DEFAULT_RL_SIT);   // Rear legs sit
  RR.write(DEFAULT_RR_SIT);
}

void wave() {
  Serial.print("Hallo!");
  for (int i = 0; i < 3; i++) {
    Serial.print("Zwaai");
    FL.write(WAVE_DOWN);
    delay(500); // Add delay for a visible wave
    FL.write(WAVE_UP);
    delay(500); // Add delay for a visible wave
  }
  FL.write(DEFAULT_POS);
}

void turnRight() {
  Serial.println("Turning right");
  unsigned long startTime = millis();
  while (millis() - startTime < 5000) {
    // Adjust the servo positions for turning right
    FL.write(TURN_RIGHT_FL);  // Front left leg right turn
    FR.write(TURN_RIGHT_FR);  // Front right leg left turn
    RL.write(TURN_RIGHT_RL);  // Rear left leg left turn
    RR.write(TURN_RIGHT_RR);  // Rear right leg right turn
  }

  // Return to default position
  FL.write(DEFAULT_POS);
  FR.write(DEFAULT_POS);
  RL.write(DEFAULT_POS);
  RR.write(DEFAULT_POS);
  delay(WALK_DELAY);
}

void turnLeft() {
  Serial.println("Turning left");
  unsigned long startTime = millis();
  while (millis() - startTime < 5000) {
    // Adjust the servo positions for turning left
    FL.write(TURN_LEFT_FL);   // Front left leg left turn
    FR.write(TURN_LEFT_FR);   // Front right leg right turn
    RL.write(TURN_LEFT_RL);   // Rear left leg right turn
    RR.write(TURN_LEFT_RR);   // Rear right leg left turn
  }

  // Return to default position
  FL.write(DEFAULT_POS);
  FR.write(DEFAULT_POS);
  RL.write(DEFAULT_POS);
  RR.write(DEFAULT_POS);
  delay(WALK_DELAY);
}


void checkForCommand() {
  static String messageBuffer;

  if (client.connected()) {
    while (client.available()) {
      char c = client.read();
      messageBuffer += c;
    }

    if (!messageBuffer.isEmpty()) {
      // Print the received message
      Serial.println("Received message:");
      Serial.println(messageBuffer);

      // Decode the JSON message
      StaticJsonDocument<200> jsonDoc; // Adjust the size according to your message
      DeserializationError error = deserializeJson(jsonDoc, messageBuffer);

      if (error) {
        Serial.print("deserializeJson() failed: ");
        Serial.println(error.c_str());
      } else {
        // Extract the command from the JSON object
        const char* command = jsonDoc["task"];
        const char* value = jsonDoc["value"];

        currentCommand = String(command);
        currentValue = String(value);

        Serial.println("Doing task : " + currentCommand + ", with value: " + currentValue);
      }

      messageBuffer = "";
    }
  }
}

void loop() {
  walkForward();
  // if (!isConnected) {
  //   Serial.println("Attempting to connect to server...");
  //   if (client.connect(server_ip, server_port)) {
  //     Serial.println("Connected to server");
  //     isConnected = true;
  //   } else {
  //     Serial.println("Connection to server failed, retrying in 1 second...");
  //     delay(1000); // Wait before retrying
  //   }
  // }

  // if (client.connected()) {
  //   // Check for new commands
  //   checkForCommand();

  //   // Execute commands based on the current command
  //   if (currentCommand == "forward") {
  //     walkForward();
  //   } else if (currentCommand == "start") {
  //     moveToStartPosition();
  //     currentCommand = ""; // Clear the command after execution
  //   } else if (currentCommand == "lie") {
  //     lieDown();
  //     currentCommand = ""; // Clear the command after execution
  //   } else if (currentCommand == "sit") {
  //     sit();
  //     currentCommand = ""; // Clear the command after execution
  //   } else if (currentCommand == "wave") {
  //     wave();
  //     currentCommand = ""; // Clear the command after execution
  //   } else if (currentCommand == "right") {
  //     turnRight();
  //     currentCommand = ""; // Clear the command after execution
  //   } else if (currentCommand == "left") {
  //     turnLeft();
  //     currentCommand = ""; // Clear the command after execution
  //   }
  // } else {
  //   isConnected = false;
  //   Serial.println("Disconnected from server, attempting to reconnect...");
  // }
}

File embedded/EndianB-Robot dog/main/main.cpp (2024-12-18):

#include <Arduino.h>
#include <ESP32Servo.h>
#include <WiFiManager.h>
#include <WiFiClient.h>
#include <ArduinoJson.h>
#include <Wire.h>
#include <Adafruit_GFX.h>

#include "Face.h"
#include "movement/movement.h"
#include "wifimanager/wifi_manager.h"
#include "websocket/websocket_handler.h"

// WiFi and server details
const char *server_ip = "192.168.178.66"; // IP address of the server to connect to
const uint16_t server_port = 8080;        // Port number of the server to connect to

Movement movement(18, 16, 17, 5); // Initialize the movement object

Face Face; // Initialize the face object

WiFiManagerHelper wifiManagerHelper;              // Initialize the Wi-Fi manager helper object
bool isConnected = false;                         // Boolean flag to track connection status
WebSocketClient wsClient(server_ip, server_port); // Initialize the WebSocket client object




enum Command
{
  FORWARD,
  BACKWARD,
  LEFT,
  RIGHT,
  SIT,
  LIE,
  WAVE,
  DANCE,
  START,
  UNKNOWN
};

// Preset angles for lying down position
#define PRESET_FL_LIE 0
#define PRESET_FR_LIE 180
#define PRESET_RL_LIE 180
#define PRESET_RR_LIE 0

// Preset angles for waving
#define WAVE_DOWN 30
#define WAVE_UP 0

// Turning presets
#define TURN_DELAY 600 // Delay between turn steps

#define TURN_RIGHT_FL 60
#define TURN_RIGHT_FR 120
#define TURN_RIGHT_RL 120
#define TURN_RIGHT_RR 60

#define TURN_LEFT_FL 120
#define TURN_LEFT_FR 60
#define TURN_LEFT_RL 60
#define TURN_LEFT_RR 120

// I2C-address of the MPU-9250 sensor
#define SENSOR_ID (0x68)

// Address of the configuraton register of the sensor
#define FIFO_ENABLE (0x23)

// Addresses of the data registers to read
#define TEMP_OUT_H (0x41)
#define TEMP_OUT_L (0x42)

#define ACCEL_XOUT_H (0x3B)
#define ACCEL_XOUT_L (0x3C)
#define ACCEL_YOUT_H (0x3D)
#define ACCEL_YOUT_L (0x3E)
#define ACCEL_ZOUT_H (0x3F)
#define ACCEL_ZOUT_L (0x40)

#define GYRO_XOUT_H (0x43)
#define GYRO_XOUT_L (0x44)
#define GYRO_YOUT_H (0x45)
#define GYRO_YOUT_L (0x46)
#define GYRO_ZOUT_H (0x47)
#define GYRO_ZOUT_L (0x48)

String currentCommand = ""; // String to store the current command

// OLED display definitions
#define SCREEN_WIDTH 128 // OLED display width, in pixels
#define SCREEN_HEIGHT 64 // OLED display height, in pixels

// I2C address of the OLED display
#define SSD1306_I2C_ADDRESS 0x3C

// Include separate bitmap header files
#include "bitmapForFace/smile_bitmap.h"
#include "bitmapForFace/frown_bitmap.h"
#include "bitmapForFace/idle_bitmap.h"

/**
 * @brief Write a value to a specific register on the MPU-9250 sensor
 *
 * @param registerAddress
 * @param value
 */
void writeToRegister(uint8_t registerAddress, uint8_t value)
{
  Wire.beginTransmission(SENSOR_ID);
  Wire.write(registerAddress);
  Wire.write(value);
  Wire.endTransmission();
}

void setup()
{
  Serial.begin(115200); // Initialize serial communication at 115200 baud

  bool face_result = Face.Initialize(SCREEN_WIDTH, SCREEN_HEIGHT, SSD1306_I2C_ADDRESS);
  wifiManagerHelper.connectToWiFi();
  wsClient.Connect();

  Serial.println(WiFi.localIP());


  // Connect to Wi-Fi
  if (!wifiManagerHelper.connectToWiFi())
  {
    Serial.println("Wi-Fi connection failed");
    ESP.restart(); // Restart ESP32 if Wi-Fi connection fails
  }

  // Connect to the server
  if (!wsClient.IsConnected())
  {
    Serial.println("Failed to connect to the server");
    wsClient.Reconnect();
  }

  // Initialize the servos
  movement.initServos();

  delay(3000); // Wait for 3 seconds

  // TODO: Figure out where this 'Wire' comes from...
  Wire.begin(4, 15); // SDA on pin 4, SCL on pin 15

  // Initialize the MPU-9250 sensor
  writeToRegister(FIFO_ENABLE, 0b11111000);

  Face.DisplayFace(128, 64, BM_IDLE);
}

void setFace(String command)
{
  if (command == "sit" || command == "lie")
  {
    Face.DisplayFace(128, 64, BM_FROWN);
  }
  else if (command == "forward" || command == "backward" || command == "dance" || command == "dance")
  {
    Face.DisplayFace(128, 64, BM_SMILE);
  }
  else if (command == "wave")
  {
    Face.DisplayFace(128, 64, BM_IDLE);
  }
}

/**
 * @brief Read data from a specific I2C register on the MPU-9250 sensor
 *
 * @param registerAddress address of the target register
 * @return one byte of available data, otherwise 0
 */
int readFromRegister(uint8_t registerAddress)
{
  Wire.beginTransmission(SENSOR_ID);
  Wire.write(registerAddress);    // Write address of target register
  Wire.endTransmission(false);    // End transmission without closing connection
  Wire.requestFrom(SENSOR_ID, 1); // Request 1 byte

  if (Wire.available())
  {
    return Wire.read(); // Read and return the byte
  }
  else
  {
    return 0; // Return 0 if no data is available
  }
}

Command getCommand(const String &command)
{
  if (command == "forward")
    return FORWARD;
  if (command == "backward")
    return BACKWARD;
  if (command == "left")
    return LEFT;
  if (command == "right")
    return RIGHT;
  if (command == "sit")
    return SIT;
  if (command == "lie")
    return LIE;
  if (command == "wave")
    return WAVE;
  if (command == "dance")
    return DANCE;
  if (command == "start")
    return START;
  return UNKNOWN;
}

void handleCommand(String command)
{
  switch (getCommand(command))
  {
  case FORWARD:
    movement.walkForward();
    break;
  case BACKWARD:
    movement.walkBackward();
    break;
  case UNKNOWN:
    Serial.println("Unknown command");
    break;
  }
}

void loop()
{

  // Read data from the server
  if (!wsClient.IsConnected())
  {
    wsClient.Reconnect();
  }

  if (wsClient.IsConnected())
  {
    String command = wsClient.ReadData();
    Serial.println("Received command: " + command);
    setFace(command);
    handleCommand(command);
  }

  delay(10);
}

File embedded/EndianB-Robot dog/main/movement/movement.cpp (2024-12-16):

#include "movement/movement.h"

// Constructor
Movement::Movement(int flPin, int rlPin, int frPin, int rrPin)
{
    _servoPins[0] = flPin;
    _servoPins[1] = rlPin;
    _servoPins[2] = frPin;
    _servoPins[3] = rrPin;
}

// Initialize servos
void Movement::initServos()
{
    for (int i = 0; i < 4; i++)
    {
        servos[i].attach(_servoPins[i]); // Attach each servo to its pin
        servos[i].write(DEFAULT_POS);    // Set initial position
    }
    Serial.println("Servos initialized");
}

// Stop servos
void Movement::stopServos()
{
    for (int i = 0; i < 4; i++)
    {
        servos[i].write(DEFAULT_POS);
    }
}

// Left step movement
void Movement::leftStep()
{
    int leftStep[] = {90, 110, 60, 120};
    for (int i = 0; i < 4; i++)
    {
        servos[i].write(leftStep[i]);
        delay(250);
    }
}

// Right step movement
void Movement::rightStep()
{
    int leftStep[] = {90, 60, 120, 70};
    for (int i = 0; i < 4; i++)
    {
        servos[i].write(leftStep[i]);
        delay(250);
    }
}

// Walk forward
void Movement::walkForward()
{
    uint32_t startTime = millis();
    uint32_t lastStepTime = 0;
    bool isLeftStep = true;

    while (millis() - startTime < WALK_DURATION)
    {
        if (millis() - lastStepTime >= STEP_INTERVAL)
        {
            if (isLeftStep)
            {
                leftStep();
            }
            else
            {
                rightStep();
            }
            isLeftStep = !isLeftStep;
            lastStepTime = millis();
        }
    }
    stopServos();
}

// Walk backward
void Movement::walkBackward()
{
    uint32_t startTime = millis();
    uint32_t lastStepTime = 0;

    while (millis() - startTime < WALK_DURATION)
    {
        if (millis() - lastStepTime >= STEP_INTERVAL)
        {
            servos[2].write(DEFAULT_POS + FRONT_OFFSET); // RL
            servos[3].write(DEFAULT_POS - FRONT_OFFSET); // RR
            servos[1].write(DEFAULT_POS - FRONT_OFFSET); // FR
            servos[0].write(DEFAULT_POS + FRONT_OFFSET); // FL
            lastStepTime = millis();
        }
    }
    Serial.println(startTime);
    stopServos();
}

// Sit movement
void Movement::sit()
{
    int sitPosition[] = {110, 40, 70, 145};

    for (int i = 0; i < 4; i++)
    {
        servos[i].write(sitPosition[i]);
    }
}

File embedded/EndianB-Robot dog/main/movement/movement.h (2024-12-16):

#ifndef MOVEMENT_H // MOVEMENT_MOVEMENT_H
#define MOVEMENT_H // MOVEMENT_MOVEMENT_H

#include <ESP32Servo.h>

class Movement
{
public:
   // Constants
   static constexpr int DEFAULT_POS = 90;
   static constexpr int WALK_DELAY = 350;
   static constexpr int BACK_OFFSET = 35;
   static constexpr int FRONT_OFFSET = 15;
   static constexpr int STEP_INTERVAL = 300;
   static constexpr int WALK_DURATION = 5000;

   // Constructor
   Movement(int flPin, int frPin, int rlPin, int rrPin);

   // Methods to control the robot's movement
   void initServos();
   void stopServos();
   void leftStep();
   void rightStep();
   void walkForward();
   void walkBackward();
   void sit();

private:
   Servo FL, FR, RL, RR;
   Servo servos[4];
   int _servoPins[4] = {};
};

#endif // MOVEMENT_MOVEMENT_H

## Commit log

2024-04-22 Added 3D design
    Added a folder for 3D design, and added Design for endian a v0.1 + documentation for said file.
    [EndianA-V0.1.f3d]
2024-04-22 Added 3d printer batch
    [Plate.stl, Spur Gear (8 teeth).stl, Spur gear 16 teeth.stl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]
2024-04-22 created prototype web design
2024-04-25 laser cut journal luc
2024-04-25 added code from original little endian project
    [little_endian_frame.scad]
2024-04-26 Created svg of servo for future designs
2024-04-26 Created design for bottom plate of robot dog
2024-04-26 created svg outline of battery holder
2024-05-07 added buttons to html
2024-05-07 added css to buttons
2024-05-07 added javascript for buttons
2024-05-08 Added code to move servos using terminal
2024-05-08 added code to send angels to set on the servos of robot B and a program for the robot to control it with this information
2024-05-13 added BOM for every prototype and wow factor research
2024-05-13 Made folder name the same as file because Arduino IDE required it
2024-05-13 pro's and con's for servo's and steppermotors
2024-05-13 conclusion about the motor, design to hold wheel
    [rw_bike_front_fork_1x.stl, rw_bike_rear_wheel_for_tpu_tire_1x.stl, rw_bike_rear_wheel_tire2_tpu_1x.stl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]
2024-05-13 added lasercutter and eco-friendliness research stories
2024-05-15 reorderd some files into dedicated folders
    [EndianA-V0.1.f3d, Plate.stl, Spur Gear (8 teeth).stl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]
2024-05-16 updated endian A design files
    [AxelHolder.dxf, BasePlate.dxf, BigCog.dxf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]
2024-05-16 minor spelling mistake 🤓
2024-05-16 lasercut dingen
    [Body plate.dxf, axel holder.dxf, bracket.dxf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]
2024-05-24 function init servo position to put all the legs down
2024-05-24 Created wiring diagram
    [wiringdiagram.fzz]
2024-05-27 Added labels to wiring diagram
    [wiringdiagram.fzz]
2024-05-27 Added wiring diagram to documentation
2024-05-27 Added power source to wiring diagram
    [wiringdiagram.fzz]
2024-05-27 Added updated wiring diagram to documentation
2024-05-27 Added connect button and styling
2024-05-27 right button
2024-05-27 draggable button has been made and there is an drop down menu present. However, after loadDragables() the drop down menu doesn't work anymore
2024-05-27 changed servo angles
2024-05-30 Added play pause button, and documentation
2024-05-30 Added print block
2024-05-30 Added play button and made code executable
2024-05-31 Added homw button
2024-06-03 updated buttons.js
2024-06-06 changed file name and fixed rest of merge conflict
    [main.ino]
2024-06-06 documentation for soldering done
2024-06-14 Added I2C communication functions to main
2024-06-14 Added I2C functions to documentation
2024-06-17 documented LCD-mount research
2024-06-17 Added sensor data read function to main
2024-06-17 Added reading sensor data to documentation
2024-06-17 Added to BOM
2024-06-17 Added better buttons and documentation
2024-06-17 Revert "Merge branch..."
    This reverts merge request !77
    [main.ino]
2024-06-17 Improved the ui for mobile devices
2024-06-18 added comments to buttons.js
2024-06-18 added doc for buttons.js
2024-06-19 changed some minor issues for the implentations of the face
    [main.ino]
2024-06-20 Changed buttons
2024-06-21 Added more parts to BOM
2024-06-21 Added even more parts to BOM
2024-06-21 Added screws and bolts to BOM
2024-06-21 added assembly tutorial
2024-06-24 updated recommendations and lcd-mount documentation
2024-06-24 Added accelerometer recommendation
2024-06-25 small update to assembly guide and index
2024-06-25 Added power switch recommendation
2024-06-25 Updated wiring diagram with voltage regulator and display
    [wiringdiagram.fzz]
2024-06-25 Added screenshot of updated wiring diagram
2024-06-25 iets anders aan de sessions
2024-06-25 expanded assembly guide, needs pictures
2024-06-25 new 30x60 acryllic plate
2024-06-25 completed assembly_guide.md
2024-06-26 small fix to assembly_guide
2024-06-26 failure with the legs
2024-06-26 added servo recommendations
2024-11-26 Updated index, changes in description
    - Removed index.css which was a copy of style.css and only used on the index
    - Added Open Sans font to fit HvA housestyle
    - Changed --hva-color-light variable in CSS to fit HvA housestyle
    - Removed home button in top left of navbar and integrated it with HvA image
    - Made connection drawer at the bottom of the page look nicer
2024-11-26 Added animations to buttons
2024-11-26 feat: created a button in the frontend
2024-11-26 feat: rewrote sit position so that it's more readable
    [little_endian_frame.scad]
2024-11-27 Added an arrow button
2024-11-28 Updated some bugs in the main code and made walking forward
    Walking forward in a seperate header file
    [main.cpp, walking.h]
2024-11-28 CHANGE
    -make stopping servos into reusable function, use millis for non blocking wait. Updated documentation
2024-12-02 Created the homepage prototype
2024-12-05 Removed leftover code from the home button
2024-12-05 added button for css
2024-12-05 added html container for the button
2024-12-08 Wrote about abstracting the inner workings of the leg
2024-12-08 Added a code snippet to showcase the leg
2024-12-08 removed code from buttons.css
2024-12-13 Have also added hovers for the button
2024-12-16 Updated: sit funtion, fixed main.cpp and moved unused files to old folder
    [RobotDog.ino]
2024-12-16 Updated: servo angles in docs
2024-12-16 UPDATE button.js reads local var robotId
    sends robotid to the server
2024-12-17 Changed: NavBar.html to look like a navigation bar instead of buttons
